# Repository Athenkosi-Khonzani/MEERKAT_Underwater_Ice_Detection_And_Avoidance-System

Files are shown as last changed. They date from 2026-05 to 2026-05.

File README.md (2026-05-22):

# MEERKAT — Underwater Ice Detection and Avoidance System

MEERKAT is a small, low-cost Autonomous Underwater Vehicle (AUV) designed to detect and avoid sub-surface ice (frazil ice, brash ice, and submerged keels of icebergs) in turbid polar waters. The platform descends and ascends using a **Variable Buoyancy System (VBS)** — a syringe driven by two DC motors — rather than thrusters, which keeps power consumption low and the acoustic signature small.

This repository contains the full design package: mechanical CAD, the power-electronics PCB, and the embedded firmware that runs the vehicle.

---

## System Architecture

MEERKAT is divided into four independent subsystems. Each lives in its own folder and has its own README with the wiring, build, and flashing details.

```
                      ┌──────────────────────────────┐
                      │      Surface ESP32           │
                      │  (mission start / telemetry) │
                      └──────────────┬───────────────┘
                                     │ UART (115200 8N1)
                                     │ JSON telemetry  /  "M:1" mission cmd
                ┌────────────────────┴────────────────────┐
                │   Control & Actuation Subsystem (F446)  │
                │   Mission state machine, motor PWM,     │
                │   VBS limit logic, battery monitoring   │
                └─┬──────────────┬──────────────┬─────────┘
                  │ I²C          │ UART         │ PWM
                  │              │              │
        ┌─────────▼────────┐ ┌───▼────────┐ ┌──▼───────────────┐
        │  INA219          │ │ DYP-L08    │ │ Dual DC motors   │
        │  (pack V / I)    │ │ Ultrasonic │ │ on VBS syringe   │
        └──────────────────┘ │ (obstacle) │ └──────────────────┘
                             └────────────┘
                  │ I²C
        ┌─────────▼────────────┐
        │  VL53L1X ToF         │
        │  (plunger position)  │
        └──────────────────────┘

        ┌──────────────────────┐    ┌──────────────────────┐
        │  Power Subsystem     │    │  Housing Subsystem   │
        │  3S Li-ion + TPS5430 │    │  Pressure vessel +   │
        │  → 5 V & 3V3 rails   │    │  motor / VBS mounts  │
        └──────────────────────┘    └──────────────────────┘
```

| Subsystem | What it does | Tech |
|---|---|---|
| **Control & Actuation** | Mission state machine; drives the VBS motors; reads sensors; speaks to the surface ESP32. | STM32F446RET6 (Nucleo-F446RE), STM32CubeIDE, HAL |
| **Sensory** | Stand-alone test firmware for the two ranging sensors used on the vehicle. | STM32F051C6T6, STM32CubeIDE, HAL |
| **Power** | 3S Li-ion pack regulated to a 5 V and a 3.3 V rail; INA219 pack monitor; SoC estimator firmware module. | KiCad 7, TPS5430DDAR buck regulators, INA219 |
| **Housing** | Watertight pressure vessel with separate compartments for the battery, two veroboards, and the syringe / motor assembly. | SolidWorks (`.SLDPRT`) |

---

## Mission Concept of Operations
 
1. **Surface idle.** Pack voltage is monitored. The vehicle waits for a `"M:1"` command from the surface ESP32 over UART3.
2. **Pre-descent check.** The plunger is forced to its minimum position (syringe empty of water). If the battery is below the warning threshold, the mission is refused.
3. **Descend.** The motor is driven forward through the H-bridge; the plunger is pushed out to its maximum position, the syringe pulls water in, and the vehicle sinks.
4. **Submerged loop.** The vehicle stays down for a configurable mission time. Throughout, it:
   * streams JSON telemetry to the surface every 500 ms (SoC, ToF, sonar, MCU temperature),
   * watches the upward-looking DYP-L08 ultrasonic for obstacles closer than 1 m,
   * watches the battery and aborts to ascent if SoC < 20 %.
5. **Ascend.** Once the mission timer expires *and* the path above is clear, the motor is driven in reverse through the H-bridge — the plunger is pulled back in, the syringe expels water, and the vehicle rises. If an obstacle is detected above, the ascent waits for it to clear.
The state machine is implemented in `Control And Actuation Subsystem/Control_System_2.0/Core/Src/main.c`.

---

## Repository Layout

```
.
├── Control And Actuation Subsystem/   # STM32CubeIDE project — main flight firmware
├── Sensory Subsystem/                 # STM32CubeIDE project — sensor bring-up firmware
├── Power Subsystem/                   # KiCad PCB project + SoC estimator source
└── Housing Subsystem/                 # SolidWorks part files for the pressure vessel
```

Each folder has its own README that covers wiring, build instructions, and any setup gotchas. Start there for hands-on work.

---

## Getting Started

### Firmware (Control & Sensory)
1. Install **STM32CubeIDE 1.13** or later.
2. `File → Open Projects from File System…` and point it at the `Control_System_2.0` or `Sensor_Test` folder.
3. Build (`Project → Build All`).
4. Connect the ST-Link, then `Run → Debug` to flash.

The Control subsystem expects a **one-shot calibration** the very first time it is flashed onto a new board — the procedure is documented in its README and is gated by an `#ifdef`-style block in `main.c`.

### PCB (Power)
1. Install **KiCad 7** or later.
2. Open `Power Subsystem/PCB/KHNATH002_Power_System/KHNATH002_Power_System.kicad_pro`.
3. The fabrication outputs for JLCPCB are under `jlcpcb/`.

### Mechanical (Housing)
The parts are `.SLDPRT` files for **SolidWorks 2022** or later. They have not yet been packaged into an assembly file — open each part individually.

---

## Status

| Subsystem | Hardware | Firmware | Verified end-to-end |
|---|:---:|:---:|:---:|
| Control & Actuation | ✅ | ✅ | ✅ |
| Sensory | ✅ | ✅ | ✅ |
| Power | ✅ | ✅ | ⚠️ bench-tested only |
| Housing | ✅ | n/a | ⚠️ dry-fit only |

---

## Authors

EEE4113F project, University of Cape Town, Department of Electrical Engineering.

* Athenkosi Khonzani — Power Subsystem 
* Ayanda Madlala — Housing Subsystem 
* Branden Nkhahle — Sensory Subsystem
* Manelisi Ngcobo — Control And Actuation Subsystem

---

## License

Unless otherwise noted, source code is provided as-is for academic use. STM32 HAL drivers are distributed under their original STMicroelectronics license (see `Drivers/` directory in each firmware project).

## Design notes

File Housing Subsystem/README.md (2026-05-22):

# MEERKAT AUV: Housing Subsystem

## Overview
This subsystem is the **mechanical pressure vessel** for the MEERKAT AUV. Its job is to keep the electronics, the battery, and the Variable Buoyancy System (VBS) syringe dry while the vehicle is submerged, and to provide a rigid mounting point for the single DC motor that drives the VBS plunger.

All parts are designed in **SolidWorks** (version 2022 or later). They are supplied as individual `.SLDPRT` files — there is no master `.SLDASM` assembly in the repo yet.

---

## Parts in this Folder

| File | Purpose |
|---|---|
| `FullBody.SLDPRT` | Outer cylindrical hull of the AUV. Defines the overall envelope and the end-cap interfaces. |
| `Imporved Upper Lid.SLDPRT` | Top end cap. Carries the through-hull port for the **upward-looking ultrasonic sensor** (used during ascent to check the path is clear of ice). *(filename typo preserved for git history.)* |
| `Improved lowe lid.SLDPRT` | Bottom end cap. Mounts the `Circular motor holder` on its inner face and provides the wet-side opening for the VBS syringe. *(filename typo preserved for git history.)* |
| `Circular motor holder.SLDPRT` | Bulkhead bracket fixed to the lower lid; locates and clamps the **single DC motor** that drives the VBS syringe plunger. |
| `Compartment battery.SLDPRT` | Internal tray that holds the 3S Li-ion pack and keeps it isolated from the veroboards. |
| `Compartment 2 veroboard.SLDPRT` | Internal mounting tray for the power-electronics veroboard (regulators + INA219). |
| `Compartment3 veroboard.SLDPRT` | Internal mounting tray for the Control & Actuation veroboard (STM32F446 carrier + sensor breakouts). |

---

## Internal Layout

The hull is divided into three stacked compartments along its axis, with the motor and VBS syringe mounted at the bottom:

```
   ┌──────────────────────────────────────────────────────────┐
   │                  Upper Lid                               │  ← upward-looking ultrasonic port
   ├──────────────────────────────────────────────────────────┤
   │   Compartment 3   — Control veroboard (STM32F446 + I/O)  │
   ├──────────────────────────────────────────────────────────┤
   │   Compartment 2   — Power veroboard (TPS5430 + INA219)   │
   ├──────────────────────────────────────────────────────────┤
   │   Battery Compartment — 3S Li-ion pack                   │
   ├──────────────────────────────────────────────────────────┤
   │                  Lower Lid                               │  ← carries Circular Motor Holder
   │   Circular Motor Holder — 1 × DC motor → VBS syringe     │
   └──────────────────────────────────────────────────────────┘
```

The arrangement keeps the **heaviest component (battery) low** to give the vehicle a stable righting moment, and isolates the **noisy power electronics** in their own compartment so they do not couple into the sensor / MCU veroboard above. Mounting the motor and VBS at the bottom also keeps the wet-side syringe opening submerged for the entire mission.

---

## Sealing Strategy
* End caps mate against the outer body via an **O-ring face seal** on each lid.
* The **upper lid** carries the upward-looking ultrasonic sensor — its housing is sealed against the lid, and a cable gland alongside it passes the sensor's power and signal wires into the dry compartment below.
* The **lower lid** carries the VBS syringe opening (wet side) and the through-bolts that hold the `Circular motor holder` against its dry-side face.
* The motor holder itself is **internal only** — it is not a sealing surface; it just constrains the motor body axially and radially so the plunger reaction force does not deflect it.

---

## Manufacturing Notes
* The lids and internal compartments are intended for **3D printing** (PLA or PETG for prototypes, ABS or nylon for water trials).
* The cylindrical `FullBody` is a **PVC pipe section** that the lids press into — the part file captures the inner diameter against which the lid O-rings seal.
* Allow O-ring squeeze of **15–20 %** when you print final lids; PLA prints loose by ~0.2 mm on diameter.

---

## Opening the Files
1. Open **SolidWorks 2022** or later.
2. `File → Open` and select any `.SLDPRT`.
3. Each part is self-contained and has no external references — they can be opened in any order.

If you build an assembly, recommended mate order:
1. Insert `FullBody` (fix in space).
2. Mate the two lids to its end faces.
3. Mate `Circular motor holder` against the **inner face of the lower lid**.
4. Stack the three compartment trays inside the body, working upward from the battery tray.

---

## Status & Known Issues
* Two part filenames have typos (`Imporved`, `lowe`) — preserved to avoid breaking git history. Renaming them is safe but should be done in a single commit and announced to anyone with the repo open.
* The repo does **not yet contain a top-level assembly file** (`.SLDASM`) or a drawing pack (`.SLDDRW`). These should be added before the design is taken to manufacturing.
* No tolerance analysis has been documented for the O-ring grooves yet — verify against the supplier's recommended squeeze before committing to a print.
* The motor-holder bracket has been dry-fit only; it has not been tested under the full single-motor plunger reaction force in water.

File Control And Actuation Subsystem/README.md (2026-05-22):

# MEERKAT AUV: Control & Actuation Subsystem Firmware (STM32F446RE)

## Overview
This is the **flight firmware** for the MEERKAT Autonomous Underwater Vehicle (AUV). It runs on an STM32F446RET6 (Nucleo-F446RE) and is responsible for the full mission state machine:

* Receiving the mission-start command from the surface ESP32.
* Driving the **Variable Buoyancy System (VBS)** — two DC motors that push and pull a syringe plunger — to descend and ascend.
* Reading the **VL53L1X ToF** sensor as a software-defined limit switch on the plunger.
* Reading the **DYP-L08-V2.0 ultrasonic** sensor for obstacle / ice detection on the ascent path.
* Reading the **INA219** to track battery State of Charge (SoC) and abort the mission if it drops below threshold.
* Streaming JSON telemetry back to the surface every 500 ms.

The project is built with **STM32CubeIDE** against the STM32F4 HAL.

---

## Hardware & Pin Configuration (.ioc mapping)

The target is `STM32F446RETx`. Pin assignments are taken from `Control_System_2.0.ioc` and `Core/Inc/main.h`.

### 1. VL53L1X ToF Sensor (I²C2) — plunger position
* SCL: **PB10** (I2C2_SCL)
* SDA: **PC12** (I2C2_SDA)
* XSHUT: **PA8** (`XShunt_Pin`, GPIO output — pulsed low/high in `main()` to release the sensor from reset)
* I²C address: `0x52` (8-bit shifted)

### 2. INA219 Battery Monitor (I²C1)
* SCL: **PB8** (I2C1_SCL)
* SDA: **PB7** (I2C1_SDA)
* I²C address: `0x40` (7-bit) → `0x80` (8-bit)

### 3. DYP-L08-V2.0 Ultrasonic Sensor (USART1)
* TX (MCU → sensor trigger): **PA9** (USART1_TX)
* RX (sensor → MCU 4-byte frame): **PA10** (USART1_RX)
* Baud rate: **115 200, 8N1**
* Protocol: MCU writes `0x55` to trigger; sensor responds with `[0xFF][D_H][D_L][SUM]`.

### 4. VBS Motor Drive (TIM3 / TIM4 PWM)
* Motor 1 PWM (push plunger → **descend**): **PA6** (TIM3_CH1) → `TIM3->CCR1`
* Motor 2 PWM (pull plunger → **ascend**): **PB6** (TIM4_CH1) → `TIM4->CCR1`
* Setting `CCR = 1599` drives the motor at full duty; `CCR = 0` brakes / stops.

### 5. Surface ESP32 Link (USART3)
* TX (telemetry out): **PC10** (USART3_TX)
* RX (mission-cmd in): **PC5** (USART3_RX, asynchronous)
* Baud rate: **115 200, 8N1**
* RX interrupt is armed in `MissionRx_Init()` — when `"M:1\n"` arrives, the global `missionInit` flag is set.

### 6. User Interface
* User button (Nucleo B1): **PC13** (`Pushbutton_Pin`, EXTI13, falling edge) — alternative way to start the mission via `HAL_GPIO_EXTI_Callback()`.
* Status LED (Nucleo LD2): **PA5** (`LD2_Pin`) — solid ON during the active mission, used as the calibration prompt LED.

### 7. Debugging (SWD)
* SWDIO: **PA13**, SWCLK: **PA14**, SWO: **PB3** — locked open in CubeMX so the ST-Link cannot be locked out.

### 8. MCU Internal Temperature
* **ADC1** sampling the internal `ADC_CHANNEL_TEMPSENSOR` via DMA — used for the `mcu_temp` field in telemetry.

### 9. Real-Time Clock
* **LSE** crystal on **PC14/PC15** drives the RTC, which timestamps the mission duration.

---

## Mission State Machine (`main.c`)

The flight loop in `main()` implements the following gated flow. Each iteration begins with a fresh RTC snapshot, `UpdateSensors()`, and a non-blocking `Telemetry_Tick()`.

```
                ┌────────────────────────────────┐
                │ Wait for missionInit ("M:1")   │
                └──────────────┬─────────────────┘
                               │
                ┌──────────────▼─────────────────┐
                │ Battery enough?  (SoC > 30 %)  │── no ──► stop_motor(); maybe ascend()
                └──────────────┬─────────────────┘
                               │ yes
                ┌──────────────▼─────────────────┐
                │ Plunger at MIN?                │── no ──► Force_plunger_min(); loop
                └──────────────┬─────────────────┘
                               │ yes
                ┌──────────────▼─────────────────┐
                │ descend()  — TIM3 PWM full     │
                └──────────────┬─────────────────┘
                               │
                ┌──────────────▼─────────────────┐
                │ Submerged dwell loop           │
                │  while !mission_complete       │
                │        && SoC >= 20 %          │
                └──────────────┬─────────────────┘
                               │ timer / battery
                ┌──────────────▼─────────────────┐
                │ ascend()  — TIM4 PWM, blocks   │
                │ if sonar_dist < 1000 mm        │
                └────────────────────────────────┘
```

Key constants in `main.c`:
* `MIN = 65`, `MAX = 100` — VBS plunger limits in mm (linear ToF reading after calibration).
* Sonar safety threshold: ascent will not proceed if `sonar_dist <= 1000 mm`.
* Mission timeout: currently `30 s` (line `if (time_elapsed >= 30)`) — change here to extend dives.
* `TELEM_PERIOD_MS = 500` — telemetry packet rate.

---

## Core File Structure

### `main.c`
The mission state machine described above. Hosts the helpers `stop_motor()`, `Force_plunger_min()`, `descend()`, `ascend()`, and `UpdateSensors()`. It also contains a **one-shot ToF calibration routine** (`RunOneShotCalibration()`) which is normally commented out — see the *First-Flash Calibration* section below.

### `ToF.c` / `ToF.h`  (`Core/Inc/`)
Driver and calibration logic for the VL53L1X.
* **Two-point linear calibration.** Reference points are `TOF_CAL_NEAR_REF_MM = 60` and `TOF_CAL_FAR_REF_MM = 120`. The driver averages `TOF_CAL_SAMPLES = 50` raw samples at each point and computes a slope/offset that maps the sensor's distorted reading inside the syringe housing to true millimetres.
* **Persistent storage.** Slope and offset are saved through `FlashStore_*` to **Flash Sector 7** (`0x08060000`) so calibration survives a power cycle.
* Both raw and calibrated reads are exposed (`ToF_ReadDistanceRaw()` / `ToF_ReadDistance()`).

### `Sonar.c` / `Sonar.h`  (`Core/Inc/`)
DYP-L08-V2.0 driver over UART1.
* `Sonar_GetDistance()` sends the `0x55` trigger byte, then blocks up to 100 ms waiting for the 4-byte reply.
* **Frame validation:** header byte (`0xFF`), checksum (`(uint8_t)(0xFF + D_H + D_L)`), and explicit reject of `0x0000` / `0xFFFF` out-of-range sentinels.
* Returns a structured `Sonar_Status` enum so the caller can distinguish a TX timeout from a bad checksum from a true out-of-range reading.

### `battery.c` / `battery.h`  (`Core/Inc/`)
INA219-based State-of-Charge estimator. Default configuration is for the **3S 1000 mAh Li-ion pack** used in the vehicle (full = 12.6 V, empty = 8.4 V). Combines an **OCV lookup table** (used once at boot for the initial SoC seed) with **coulomb counting** during operation. Exposes a `BatteryData_t` snapshot through `Battery_GetData()` and three status flags (`BATTERY_OK / WARNING / CRITICAL`).

### `telemetry.c` / `telemetry.h`  (`Core/Inc/`)
Builds and transmits a newline-terminated JSON telemetry packet over USART3 (to the surface ESP32). One packet contains: sequence number, SoC %, pack voltage, pack current, ToF mm, sonar mm, MCU temperature. Sentinel values `TELEM_DIST_INVALID` (`0xFFFF`) and `TELEM_TEMP_INVALID` (`-999.0`) flag unavailable sensors.

### `mission_rx.c` / `mission_rx.h`  (`Core/Inc/`)
Receives mission commands from the surface ESP32 on USART3 via interrupt. The only command currently parsed is `"M:1"`, which sets the global `missionInit` flag and unblocks the main loop.

### `temp_sensor.c` / `temp_sensor.h`  (`Core/Inc/`)
Thin wrapper around the STM32's internal temperature sensor on ADC1 (DMA-driven), returning a calibrated temperature in °C.

### `FlashStore.c` / `FlashStore.h`  (`Core/Inc/`)
Two-function persistent-storage helper (`FlashStore_Load`, `FlashStore_Save`) used by `ToF.c` to keep the calibration record across reboots. Storage lives in **Flash Sector 7** (`0x08060000`, 128 KB). The linker script (`STM32F446RETX_FLASH.ld`) must cap application FLASH at `0x60000` to keep code out of that sector — this has already been done.

> **Note:** Driver and configuration sources for the I²C, UART, RTC, ADC, and TIM peripherals were generated by CubeMX and live in `Core/Src/`. Pin assignments are described above and are the source of truth.

---

## First-Flash Calibration (one-shot, then re-flash)

The very first time you flash this firmware onto a fresh board, the ToF needs its two-point calibration captured against the **actual** syringe housing. The procedure lives in `RunOneShotCalibration()` in `main.c`:

1. Uncomment the call to `RunOneShotCalibration(&hi2c2)` in `main()`.
2. Place a flat target exactly **60 mm** from the sensor face.
3. Flash and reset. LD2 stays on for 5 s — get ready.
4. LD2 turns off and the firmware captures 50 samples (~3 s).
5. LD2 comes back on for 5 s — move the target to exactly **120 mm**.
6. LD2 turns off, 50 more samples are captured.
7. **3 quick flashes = success.** The slope/offset are saved to Flash Sector 7. Solid-on LED = failure.
8. Re-comment the `RunOneShotCalibration()` call and re-flash with the production build.

The calibration record is persistent — you do **not** need to repeat this between subsequent flashes of the production firmware unless you erase the chip or change syringe geometry.

---

## Building & Flashing

1. Open **STM32CubeIDE 1.13** or later.
2. `File → Open Projects from File System…` → select the `Control_System_2.0/` folder.
3. `Project → Build All`.
4. Plug in the Nucleo (ST-Link enumerates over USB).
5. `Run → Debug` to flash and start a debug session, or `Run → Run` to flash and detach.

The default build output is `Debug/Control_System_2.0.elf`.

---

## Quick Troubleshooting

| Symptom | Likely cause |
|---|---|
| LED blinks fast forever right after boot | `ToF_Init()` failed — check XShunt (PA8) wiring and I²C2 pull-ups on PB10/PC12. |
| LED solid on, never starts mission | `Battery_Init()` returned `HAL_ERROR` — check INA219 wiring and address (0x40) on I²C1 (PB7/PB8). |
| Vehicle never descends after `"M:1"` is sent | Plunger is already at MAX — `Force_plunger_min()` is running first; give it ~10 s. |
| Telemetry stops mid-mission | UART3 wire on PC10 disconnected, or surface ESP32 reset. |
| Vehicle stays down past mission time | Sonar reading is below 1000 mm — something is above the AUV blocking the ascent. |
| ST-Link suddenly cannot connect | SWD pins (PA13/PA14) somehow got remapped — hold the BOOT0 button on power-up to force the system bootloader, then re-flash. |

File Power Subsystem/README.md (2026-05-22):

# MEERKAT AUV: Power Subsystem

## Overview
This subsystem is the **power-distribution and monitoring** layer of the MEERKAT AUV. It takes a 3-cell (3S) Li-ion battery pack and produces the two regulated rails the rest of the vehicle needs (**5 V** and **3.3 V**), while continuously measuring pack voltage and current so the flight firmware can estimate state of charge and abort the mission before the battery dies underwater.

The deliverable is two parts:

1. A **KiCad PCB project** (`PCB/KHNATH002_Power_System/`) implementing the regulators and the INA219 monitor.
2. A **portable C firmware module** (`SOC/`) — `battery.c`/`battery.h` — that runs on the flight MCU and turns INA219 readings into a usable SoC + runtime estimate.

---

## Hardware

### Battery Pack
* **Topology:** 3S Li-ion (three 18650-format cells in series).
* **Capacity:** 1000 mAh nominal (series cells share the pack mAh, they do not multiply).
* **Voltage range:**
  * Full = 3 × 4.20 V = **12.60 V**
  * Empty (cutoff) = 3 × 2.80 V ≈ **8.4 V** (configurable via `BAT_VOLTAGE_EMPTY_V`)

### Regulators (`TPS_Regulators.kicad_sch`)
Two **TPS5430DDAR** synchronous-buck regulators step the pack voltage down to the vehicle's two rails:

| Rail | Regulator | Loads |
|---|---|---|
| **5 V** | TPS5430DDAR | DC motors (via H-bridge driver), DYP-L08 ultrasonic sensor |
| **3.3 V** | TPS5430DDAR | STM32F446 MCU, VL53L1X ToF, INA219, ESP32 link |

The TPS5430 is rated 5.5–36 V in, 3 A continuous, with an internal high-side MOSFET — chosen for the headroom over the 12.6 V pack and for the relatively low BOM cost.

> **Note:** An earlier version of the design used the **MP2338GTL** (see `Regulators.kicad_sch`). That sheet is kept in the repo for history but is **not** part of the current top sheet (`KHNATH002_Power_System.kicad_sch`). The TPS implementation is the one that goes to fab.

### Monitoring (`Monitoring.kicad_sch`)
* **INA219** — high-side I²C current/voltage monitor sitting on the pack output, before the regulators. Configured for the 32 V bus-voltage range (the 16 V range saturates on a freshly charged 3S pack) and the /8 gain (320 mV full-scale on the shunt).
* **Shunt:** 0.1 Ω, giving a 100 µA current LSB after calibration → **CAL register = 4096**.
* **I²C address:** `0x40` (7-bit).

The INA219 talks to the flight MCU over **I²C1 (PB7 / PB8)** — see the Control & Actuation Subsystem README.

---

## PCB Layout

The KiCad project lives under:

```
Power Subsystem/PCB/KHNATH002_Power_System/
├── KHNATH002_Power_System.kicad_pro      # top-level project
├── KHNATH002_Power_System.kicad_sch      # top hierarchical sheet
├── KHNATH002_Power_System.kicad_pcb      # board layout
├── TPS_Regulators.kicad_sch              # 5V + 3V3 buck regulators (active)
├── Monitoring.kicad_sch                  # INA219 pack monitor
├── Regulators.kicad_sch                  # MP2338 regulators (legacy, unused)
└── jlcpcb/                               # fabrication outputs for JLCPCB
```

Open `KHNATH002_Power_System.kicad_pro` in **KiCad 7** or later.

---

## Firmware Module — `SOC/`

`battery.c` / `battery.h` is the on-board **State-of-Charge and runtime estimator**. It is not a stand-alone program — it links into the Control & Actuation Subsystem firmware (see that subsystem's README for how it is wired in).

### Algorithm
1. **Seed.** At init, read the open-circuit pack voltage (OCV) from the INA219 and map it through a lookup table to get the starting SoC. This compensates for the unknown charge state at power-on.
2. **Coulomb count.** Every `BAT_SAMPLE_PERIOD_MS` (default 500 ms), read voltage + current, then integrate current × Δt into a running `used_mAh` figure.
3. **OCV correction.** Resting-voltage measurements are blended into the coulomb-counted SoC slowly so the estimate self-corrects over time without jumping under load.
4. **Runtime.** Remaining mAh divided by recent-average current gives a live `runtime_sec` figure exposed via `Battery_GetData()`.

### Public API
```c
HAL_StatusTypeDef Battery_Init(I2C_HandleTypeDef *hi2c);
HAL_StatusTypeDef Battery_Update(void);
void              Battery_GetData(BatteryData_t *out);
void              Battery_RuntimeToHMS(uint32_t s, uint32_t *h, uint32_t *m, uint32_t *sec);
```

### `BatteryData_t` snapshot
```c
float   soc_pct;        // 0.0 – 100.0
float   voltage_V;      // pack terminal voltage
float   current_A;      // positive = discharging
float   used_mAh;       // since boot
float   remaining_mAh;
uint32_t runtime_sec;
BatteryStatus_t status; // OK / WARNING / CRITICAL
bool    valid;
```

### Configurable thresholds (in `battery.h`)
| Macro | Default | Meaning |
|---|---|---|
| `BAT_SERIES_CELLS` | 3 | Cells in series — adjust if pack changes. |
| `BAT_CAPACITY_MAH` | 1000 | Rated pack capacity (mAh). |
| `BAT_VOLTAGE_FULL_V` | 12.60 | Full pack voltage. |
| `BAT_VOLTAGE_EMPTY_V` | 8.40 | Cutoff. |
| `BAT_VDIV_RATIO` | 1.0 | Set to your divider ratio if INA219 V+ sees less than full pack voltage. |
| `BAT_SOC_OK_THRESHOLD` | 60 % | Above this → `BATTERY_OK`. |
| `BAT_SOC_WARNING_THRESHOLD` | 30 % | Above this → `BATTERY_WARNING`. Below → `BATTERY_CRITICAL`. |
| `BAT_SAMPLE_PERIOD_MS` | 500 | Coulomb-count integration period. |

The flight firmware uses these directly:
* SoC ≤ **30 %** → motor commands refused; pre-descent gate trips.
* SoC < **20 %** → in-mission abort; vehicle ascends if the path is clear.

---

## Build & Flash (firmware module)
The module is built as part of the Control & Actuation Subsystem firmware. To use it stand-alone in another project:

1. Copy `SOC/battery.c` and `SOC/battery.h` into your project.
2. Include `"battery.h"` in your `main.c`.
3. After your I²C peripheral is initialised, call `Battery_Init(&hi2c1)`.
4. Call `Battery_Update()` in your main loop (it rate-limits itself internally).
5. Read data with `Battery_GetData(&snapshot)`.

The module depends only on the STM32 HAL I²C driver — no other RTOS or library.

---

## Voltage-Divider Note (read this before powering up)

The INA219's bus-voltage input is rated to 26 V max but its 16 V config-register mode saturates above ~16 V. The 3S pack peaks at 12.6 V, which is well inside the 26 V hardware limit — **so this design connects V+ directly to the pack**, and `BAT_VDIV_RATIO` is set to `1.0`.

If you re-spin the board with a divider (e.g. for a 4S pack), update `BAT_VDIV_RATIO` in `battery.h` to the new divider ratio so the firmware un-scales the reading correctly.

---

## Status & Known Issues
* The TPS5430 layout has been verified on the bench but **not yet integrated under load with the full vehicle**.
* `Regulators.kicad_sch` (MP2338 variant) is kept in the repo for history. It is **not** part of the current build.
* The schematic does not yet include explicit reverse-polarity protection on the battery input — a Schottky or P-FET is recommended for the next revision.

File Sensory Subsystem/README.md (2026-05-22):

# MEERKAT AUV: Sensory Subsystem Firmware (STM32F411)

## Overview
This repository contains the STM32CubeIDE project for the Sensory Subsystem of the MEERKAT Autonomous Underwater Vehicle (AUV). This subsystem provides critical internal proprioception (Variable Buoyancy System limits) and external exteroception (underwater obstacle avoidance) for the platform.

The firmware successfully integrates two primary sensors:

1. VL53L1X Time-of-Flight (ToF) Sensor: Acts as a continuous, software-defined proximity limit switch to track the linear displacement of the VBS syringe plunger (40mm to 120mm limits).
2. DYP-L08-V2.0 Ultrasonic Sensor: Provides long-range (up to 10m) acoustic obstacle and ice detection in highly turbid Antarctic waters.

## Hardware & Pin Configuration (.ioc mapping)
The project is configured for the STM32F411 microcontroller. The .ioc file contains the following critical pin mappings and peripheral configurations:

### 1. VL53L1X ToF Sensor (I2C1)
- Protocol: I2C (Address: 0x52 - 8-bit shifted)
- SCL: PB6 (or as defined in your .ioc)
- SDA: PB7 (or as defined in your .ioc)

### 2. DYP-L08-V2.0 Ultrasonic Sensor (UART2 / GPIO)
- Protocol: UART (Baud Rate: 115200, 8N1)
- Trigger Pin (Yellow Wire): PA0 (Configured as GPIO Output. MCU pulls this LOW for 1ms to trigger a ping).
- Data RX Pin (White Wire): PA3 (USART2_RX. Receives the 4-byte distance frame).

### 3. Debugging & Failsafe (SWD)
- SWDIO: PA13
- SWCLK: PA14
- Note: The debug pins are explicitly locked open in the firmware (GPIO_MODE_AF_PP, GPIO_AF0_SWJ) to prevent the ST-Link from being locked out during sleep states or clock reconfigurations.

---

## Core File Structure (/Core/Src and /Core/Inc)

### main.c
Handles the primary boot sequence, peripheral initialization, and main execution loop.
- Safe Boot Sequence: On startup, main.c checks the internal Flash memory for a saved calibration profile. If found, it bypasses setup. If missing, it forces the AUV into a calibration state, prompting the user to manually move the syringe to the 20mm and 120mm bounds.
- Hardware Failsafe: Explicitly enables the GPIOA clock and maps PA13/PA14 to the debugger immediately after the system clock configuration to prevent SWD lockouts.

### ToF.c & ToF.h
Contains the drivers, mathematical filters, and memory management for the Variable Buoyancy limit switch.
- Two-Point Linear Calibration: Calculates a dynamic multiplier (m) and offset (b) using ToF_Calibrate_TwoPoint() to mathematically eliminate optical crosstalk caused by the confined syringe housing.
- Sliding Window Median Filter: Buffers distance samples and extracts the median to reject violent optical scatter spikes before they trigger a false motor-stop.
- Non-Volatile Memory Management: Saves the m and b floats permanently into Flash Sector 5 (Address 0x08020000).

### Sonar.c & Sonar.h (or equivalent UART parsing logic)
Handles the acoustic ranging data for collision avoidance.
- Frame Parsing: Reconstructs the physical distance by bit-shifting the High and Low bytes received over UART.
- Checksum Validation: Discards corrupted UART frames to prevent erratic avoidance maneuvers.
- Moving Average Filter: Smooths incoming readings to mitigate false positives caused by localized bubble swarms or water currents.

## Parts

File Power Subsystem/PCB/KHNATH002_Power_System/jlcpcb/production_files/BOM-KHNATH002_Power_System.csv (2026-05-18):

Comment | Designator | Footprint | LCSC | Quantity
0.01u | C5,C6 | C_0603_1608Metric_Pad1.08x0.95mm_HandSolder | C57112 | 2
0.1u | C2 | C_0603_1608Metric_Pad1.08x0.95mm_HandSolder | C14663 | 1
10k | R1,R7 | R_0603_1608Metric_Pad0.98x0.95mm_HandSolder | C25804 | 2
10u | C1,C3,C4 | C_0603_1608Metric_Pad1.08x0.95mm_HandSolder | C19702 | 3
12k | R6 | R_0603_1608Metric_Pad0.98x0.95mm_HandSolder | C22790 | 1
20k | R5 | R_0603_1608Metric_Pad0.98x0.95mm_HandSolder | C4184 | 1
2m | R4 | R_2512_6332Metric_Pad1.40x3.35mm_HandSolder | C2994640 | 1
3.3k | R8 | R_0603_1608Metric_Pad0.98x0.95mm_HandSolder | C22978 | 1
4.7k | R2,R3 | R_0603_1608Metric_Pad0.98x0.95mm_HandSolder | C23162 | 2
B340A | D2,D3 | SMA_L4.3-W2.6-LS5.1-RD | C64982 | 2
INA219AIDR | U2 | SOIC-8_L4.9-W3.9-P1.27-LS6.0-BL | C138706 | 1
LED | D1 | LED_0603_1608Metric_Pad1.05x0.95mm_HandSolder | C2286 | 1
RVT1V221M0810 | U7,U8 | CAP-SMD_BD8.0-L8.3-W8.3-LS9.1-FD | C3340 | 2
SMDRI127-150MT | U5,U6 | IND-SMD_L12.5-W12.5_RLF12545T | C40000 | 2
SS-12D06L5 | U1 | SW-TH_3P-P4.70_L11.1-W12.7 | C319015 | 1
TPS5430DDAR | U3,U4 | ESOP-8_L4.9-W3.9-P1.27-LS6.0-TL-EP | C9864 | 2
Jumper_2_Open | JP3 | SolderJumper-2_P1.3mm_Open_RoundedPad1.0x1.5mm |  | 1
Jumper_2_Open | JP2 | SolderJumper-2_P1.3mm_Open_RoundedPad1.0x1.5mm |  | 1
Jumper_2_Open | JP1 | SolderJumper-2_P1.3mm_Open_TrianglePad1.0x1.5mm |  | 1
GND | GND | TestPoint_Pad_D3.0mm |  | 1
LOAD | M_LOAD | TestPoint_Pad_D3.0mm |  | 1
+12V | TP10 | TestPoint_Pad_D3.0mm |  | 1
Conn_01x02_Pin | J6 | PinHeader_1x02_P2.54mm_Vertical |  | 1
Conn_01x02_Pin | J5 | PinHeader_1x02_P2.54mm_Vertical |  | 1

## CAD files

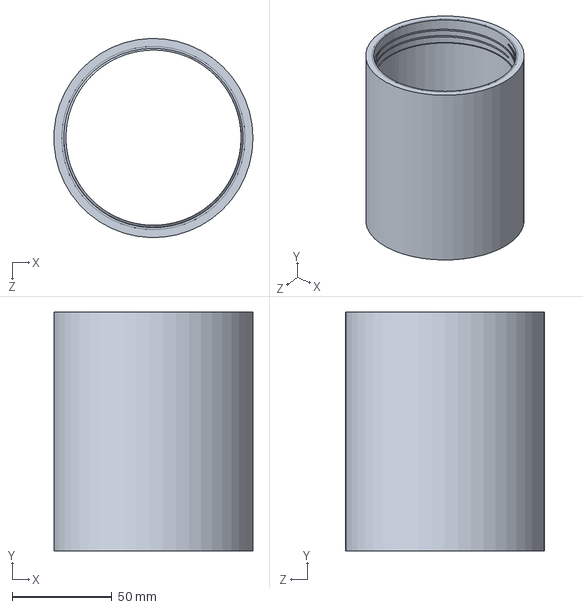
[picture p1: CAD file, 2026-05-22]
Housing Subsystem/FullBody.SLDPRT
99.9 x 120.0 x 99.9 mm

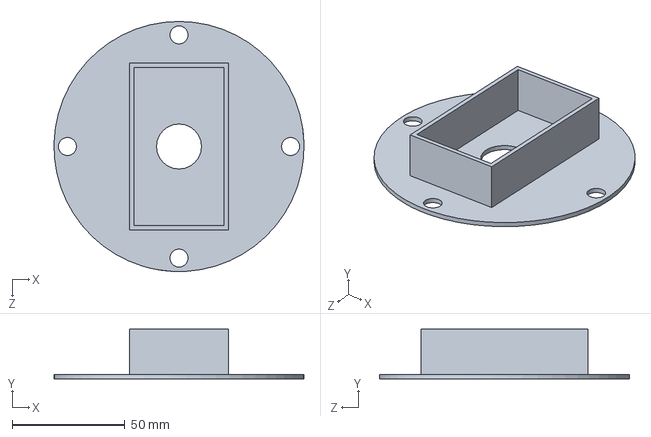
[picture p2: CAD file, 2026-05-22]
Housing Subsystem/Compartment 2 veroboard.SLDPRT
111.0 x 22.0 x 111.0 mm

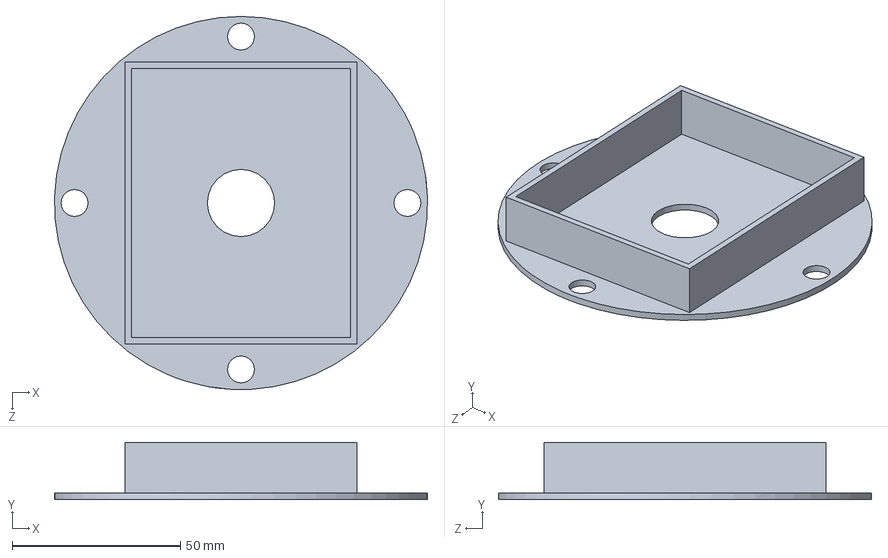
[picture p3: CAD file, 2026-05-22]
Housing Subsystem/Compartment3 veroboard.SLDPRT
111.0 x 17.0 x 111.0 mm

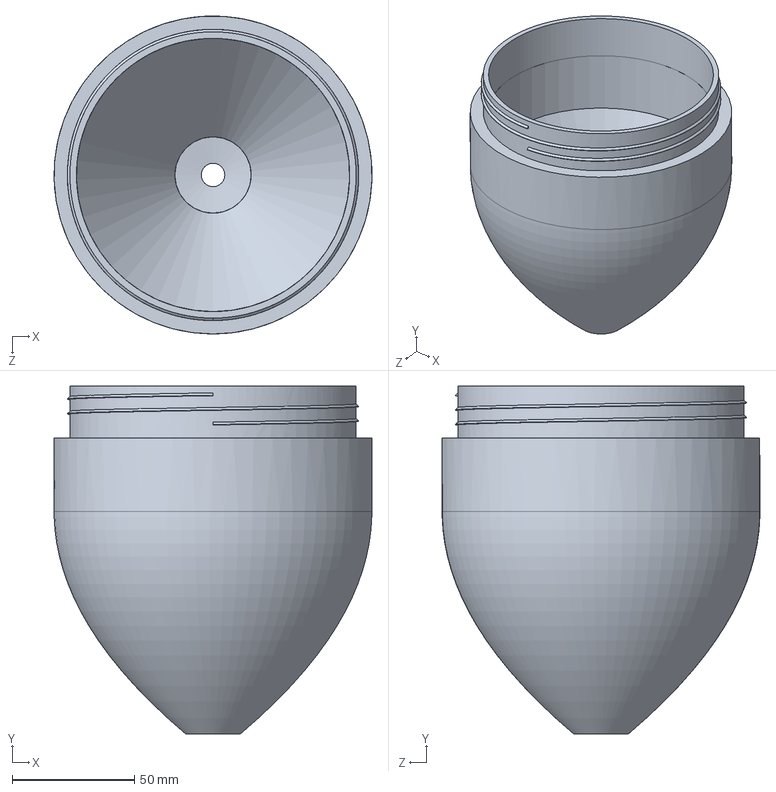
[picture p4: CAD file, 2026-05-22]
Housing Subsystem/Improved lowe lid.SLDPRT
130.0 x 142.3 x 130.0 mm

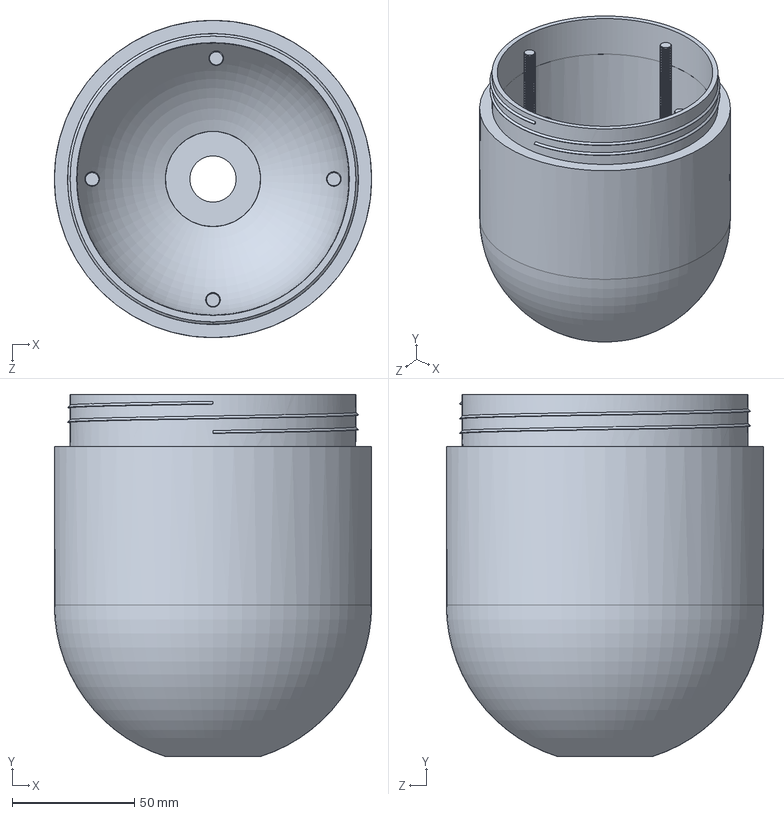
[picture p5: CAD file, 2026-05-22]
Housing Subsystem/Imporved Upper Lid.SLDPRT
130.0 x 148.3 x 130.0 mm

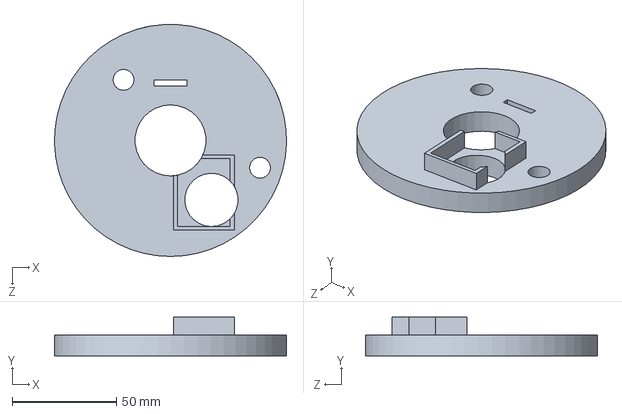
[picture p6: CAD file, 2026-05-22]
Housing Subsystem/Circular motor holder.SLDPRT
111.1 x 18.5 x 111.1 mm

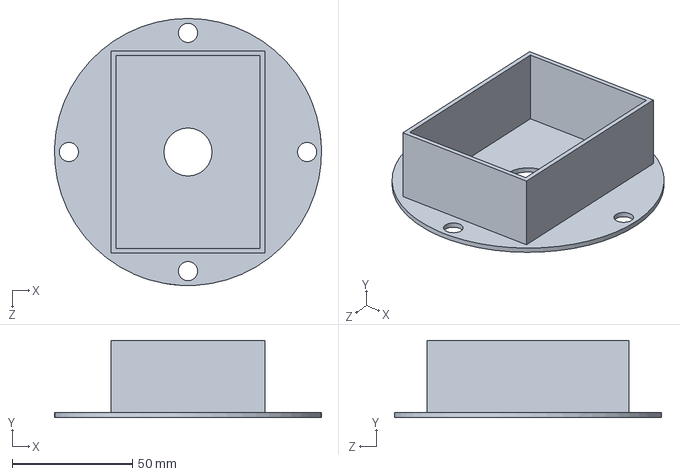
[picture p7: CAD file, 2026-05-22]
Housing Subsystem/Compartment battery.SLDPRT
111.0 x 32.0 x 111.0 mm

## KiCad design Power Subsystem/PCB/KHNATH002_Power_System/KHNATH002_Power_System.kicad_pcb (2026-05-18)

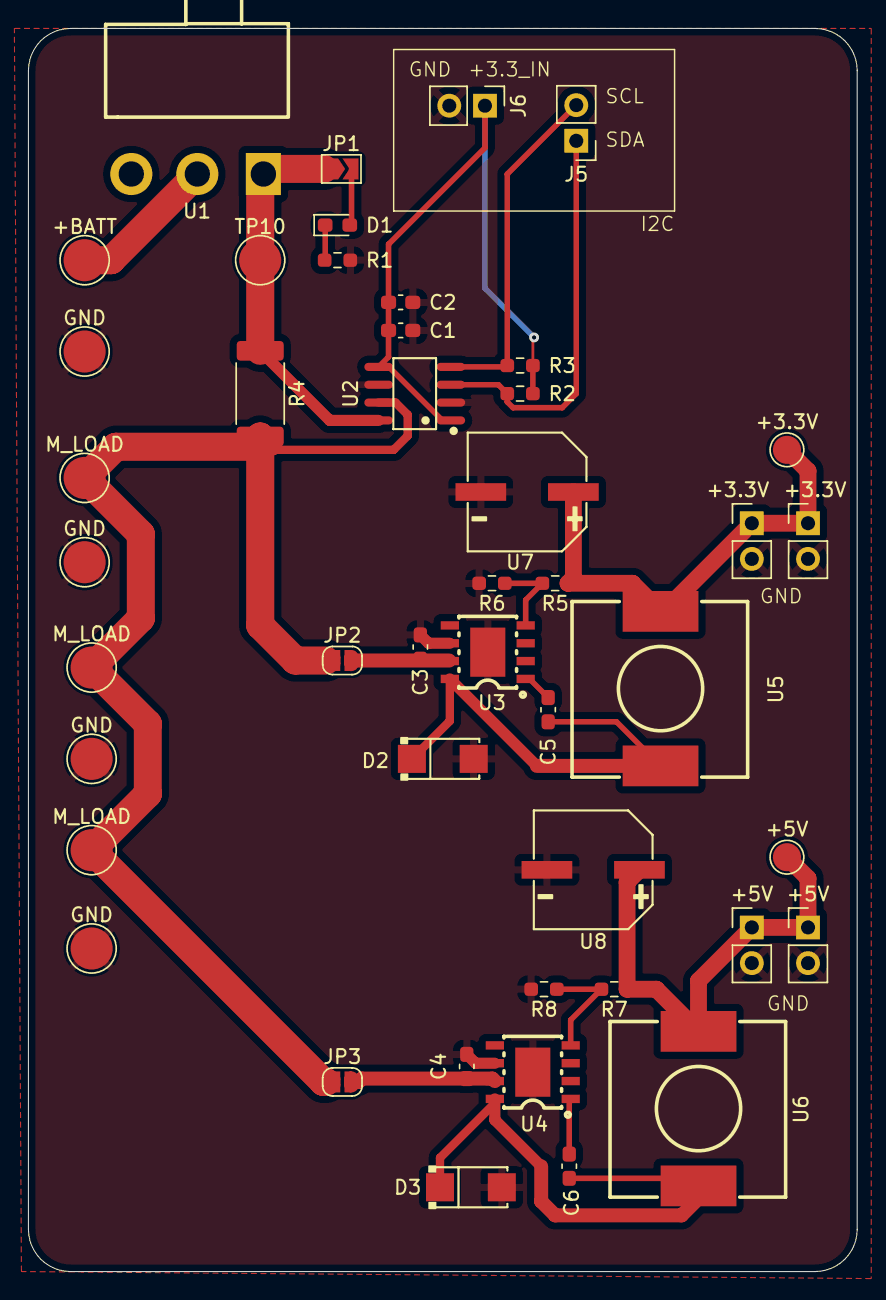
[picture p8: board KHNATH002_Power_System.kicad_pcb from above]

Board: 2 copper layers, 59.0 x 88.5 mm, 45 parts (0 on the bottom side), 19 nets.

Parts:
+3.3V: +3.3V; TestPoint_Pad_D2.0mm
+3.3V#2, +3.3V#3, +5V#2, +5V#3: Conn_01x02_Pin; PinHeader_1x02_P2.54mm_Vertical
+5V: +5V; TestPoint_Pad_D2.0mm
+BATT: +BATT; TestPoint_Pad_D3.0mm
C1, C3, C4: 10u; C_0603_1608Metric_Pad1.08x0.95mm_HandSolder
C2: 0.1u; C_0603_1608Metric_Pad1.08x0.95mm_HandSolder
C5, C6: 0.01u; C_0603_1608Metric_Pad1.08x0.95mm_HandSolder
D1: LED; LED_0603_1608Metric_Pad1.05x0.95mm_HandSolder
D2, D3: B340A; SMA_L4.3-W2.6-LS5.1-RD
GND: GND; TestPoint_Pad_D3.0mm
GND#2, GND#3, GND#4: GND; TestPoint_Pad_D3.0mm
J5, J6: Conn_01x02_Pin; PinHeader_1x02_P2.54mm_Vertical
JP1: Jumper_2_Open; SolderJumper-2_P1.3mm_Open_TrianglePad1.0x1.5mm
JP2, JP3: Jumper_2_Open; SolderJumper-2_P1.3mm_Open_RoundedPad1.0x1.5mm
M_LOAD: LOAD; TestPoint_Pad_D3.0mm
M_LOAD#2, M_LOAD#3: LOAD; TestPoint_Pad_D3.0mm
R1, R7: 10k; R_0603_1608Metric_Pad0.98x0.95mm_HandSolder
R2, R3: 4.7k; R_0603_1608Metric_Pad0.98x0.95mm_HandSolder
R4: 2m; R_2512_6332Metric_Pad1.40x3.35mm_HandSolder
R5: 20k; R_0603_1608Metric_Pad0.98x0.95mm_HandSolder
R6: 12k; R_0603_1608Metric_Pad0.98x0.95mm_HandSolder
R8: 3.3k; R_0603_1608Metric_Pad0.98x0.95mm_HandSolder
TP10: +12V; TestPoint_Pad_D3.0mm
U1: SS-12D06L5; SW-TH_3P-P4.70_L11.1-W12.7
U2: INA219AIDR; SOIC-8_L4.9-W3.9-P1.27-LS6.0-BL
U3, U4: TPS5430DDAR; ESOP-8_L4.9-W3.9-P1.27-LS6.0-TL-EP
U5, U6: SMDRI127-150MT; IND-SMD_L12.5-W12.5_RLF12545T
U7, U8: RVT1V221M0810; CAP-SMD_BD8.0-L8.3-W8.3-LS9.1-FD

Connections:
+3.3V: +3.3V.1, +3.3V#2.1, +3.3V#3.1, R5.1, U5.1, U7.1
+5V: +5V.1, +5V#2.1, +5V#3.1, R7.1, U6.1, U8.1
+12V: JP1.1 (A), R4.1, TP10.1, U1.1, U2.8 (VIN+)
+BATT: +BATT.1, U1.2
/Monitoring/+3.3_IN: C1.1, C2.1, J6.1, R2.1, R3.1, U2.1 (A1), U2.5 (VS)
/TPS_Regulators/BOOT_3.3: C5.2, U3.1 (BOOT)
/TPS_Regulators/BOOT_5: C6.2, U4.1 (BOOT)
/TPS_Regulators/PH_3.3: C5.1, D2.1 (K), U3.8 (PH), U5.2
/TPS_Regulators/PH_5: C6.1, D3.1 (K), U4.8 (PH), U6.2
/TPS_Regulators/VIN_3.3: C3.1, JP2.2 (B), U3.7 (VIN)
/TPS_Regulators/VIN_5: C4.1, JP3.2 (B), U4.7 (VIN)
/TPS_Regulators/VS_3.3: R5.2, R6.1, U3.4 (VSENSE)
/TPS_Regulators/VS_5: R7.2, R8.1, U4.4 (VSENSE)
GND: +3.3V#2.2, +3.3V#3.2, +5V#2.2, +5V#3.2, C1.2, C2.2, C3.2, C4.2, D2.2 (A), D3.2 (A), GND.1, GND#2.1, GND#3.1, GND#4.1, J6.2, R1.2, R6.2, R8.2, U2.2 (A0), U2.6 (GND), U3.6 (GND), U3.9 (PowerPAD), U4.6 (GND), U4.9 (PowerPAD), U7.2, U8.2
LOAD: JP2.1 (A), JP3.1 (A), M_LOAD.1, M_LOAD#2.1, M_LOAD#3.1, R4.2, U2.7 (VIN-)
unnamed: D1.2 (A), JP1.2 (B)
unnamed: D1.1 (K), R1.1
SCL: J5.2, R3.2, U2.4 (SCL)
SDA: J5.1, R2.2, U2.3 (SDA)

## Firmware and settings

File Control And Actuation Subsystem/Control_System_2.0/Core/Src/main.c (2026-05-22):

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
/* Includes ------------------------------------------------------------------*/
#include "main.h"

/* USER CODE BEGIN Includes */
#include "battery.h"
#include "ToF.h"
#include "Sonar.h"
#include <stdio.h>
#include "telemetry.h"
#include "temp_sensor.h"
#include "mission_rx.h"
/* USER CODE END Includes */

/* USER CODE BEGIN PTD */
/* Telemetry pacing */
#define TELEM_PERIOD_MS  500u
uint32_t last_telem_ms = 0;
/* USER CODE END PTD */

/* USER CODE BEGIN PD */
#define MIN 65 //Minimum position of plunger of 4cm
#define MAX 100 //Maximum position of plunger of 12cm
/* USER CODE END PD */

ADC_HandleTypeDef hadc1;
DMA_HandleTypeDef hdma_adc1;

I2C_HandleTypeDef hi2c1;
I2C_HandleTypeDef hi2c2;

RTC_HandleTypeDef hrtc;

TIM_HandleTypeDef htim3;
TIM_HandleTypeDef htim4;

UART_HandleTypeDef huart1;
UART_HandleTypeDef huart2;
UART_HandleTypeDef huart3;

/* USER CODE BEGIN PV */
uint32_t current_time;
BatteryData_t bat;
uint32_t prev_time;
int mission_init = 0;
uint32_t t_begin = 0;
int time_saved = 0;
uint32_t time_elapsed = 0;
uint32_t current = 0;
int mission_complete = 0;

/* ---- Live sensor state: refreshed by UpdateSensors(), readable anywhere ---- */
float    soc          = 0.0f;     /* battery state of charge, % */
uint16_t mm           = 0;        /* ToF (plunger position), mm */
uint16_t sonar_dist   = 0;        /* sonar (obstacle distance), mm */
Sonar_Handle g_sonar;             /* global sonar handle */

RTC_TimeTypeDef sTime;
RTC_DateTypeDef sDate;

/* USER CODE END PV */

void SystemClock_Config(void);
static void MX_GPIO_Init(void);
static void MX_DMA_Init(void);
static void MX_ADC1_Init(void);
static void MX_RTC_Init(void);
static void MX_TIM3_Init(void);
static void MX_TIM4_Init(void);
static void MX_USART2_UART_Init(void);
static void MX_I2C1_Init(void);
static void MX_I2C2_Init(void);
static void MX_USART1_UART_Init(void);
static void MX_USART3_UART_Init(void);
/* USER CODE BEGIN 0 */

/* Send a telemetry packet at most once every TELEM_PERIOD_MS.
   Non-blocking: returns immediately if it's not yet time. */
static void Telemetry_Tick(void)
{
    uint32_t now = HAL_GetTick();
    if ((now - last_telem_ms) < TELEM_PERIOD_MS) {
        return;
    }
    last_telem_ms = now;

    /* MCU internal temp isn't wired up here — pass the sentinel.
       If you later sample ADC1 (TEMPSENSOR channel), replace this. */
    float mcu_temp = TempSensor_ReadC();
    Telemetry_Send(&bat, mm, sonar_dist, mcu_temp);
}

static void UpdateSensors(void)
{
    /* Battery — rate-limited internally, safe to call often */
    Battery_Update();
    Battery_GetData(&bat);
    soc = bat.soc_pct;

    /* ToF (plunger position) */
    uint16_t tof = ToF_ReadDistance(&hi2c2);
    if (tof > 0) {
        mm = tof;
    }

    /* Sonar (obstacle distance) — keep last good reading on error */
    uint16_t sd = 0;
    Sonar_GetDistance(&g_sonar, &sd);
        sonar_dist = sd;

}
/*A function that stops motor from over exceeding limits*/
void stop_motor(void)
{
    TIM3->CCR1 = 0;
    TIM4->CCR1 = 0;
    UpdateSensors();   /* keep state fresh even at stop */
    Telemetry_Tick();
}

/*Function to check initial plunger position and force it to minimum so that upon mission start we can pull in water and descend*/
void Force_plunger_min(void)
{
    UpdateSensors();
    while (mm > MIN) {
        TIM4->CCR1 = 1599;
        UpdateSensors();
        Telemetry_Tick();
        /* Safety: bail out if battery dies mid-move */
        if (soc < 20) break;

        HAL_Delay(2);
    }
    stop_motor();
}

/* Push plunger to MAX (pulls water in) → platform sinks. */
void descend(void)
{
    UpdateSensors();
    while (mm < MAX) {
        TIM3->CCR1 = 1599;
        UpdateSensors();
        Telemetry_Tick();
        /* Safety: stop if battery dies */
        if (soc < 20) break;

        HAL_Delay(2);
    }
    stop_motor();
}

/* Pull plunger back toward MIN → platform rises.
   Exits early if an obstacle is detected by the sonar. */
void ascend(void)
{
    UpdateSensors();
    while (mm > MIN && sonar_dist > 1000) {
        TIM4->CCR1 = 1599;
        UpdateSensors();
        Telemetry_Tick();
        HAL_Delay(2);
    }
    stop_motor();
}



void HAL_GPIO_EXTI_Callback(uint16_t GPIO_Pin)
 {

	current_time = HAL_GetTick();
 	if ((GPIO_Pin == Pushbutton_Pin) && (current_time - prev_time > 10))
 	{


 		//TODO: Update mission initiation status
 		mission_init = 1;


 		prev_time = current_time;

 	}
 }

uint32_t to_seconds(uint8_t hours, uint8_t minutes, uint8_t seconds) {
    return (hours * 3600) + (minutes * 60) + seconds;
}

/* ============================================================
 *  ONE-SHOT CALIBRATION
 *  Comment out this whole block after running it once.
 *  ============================================================
 *  Procedure:
 *    1. Place sensor exactly TOF_CAL_NEAR_REF_MM from a flat target.
 *    2. Power on / reset — onboard LED stays ON for 5 s (get ready).
 *    3. LED blinks fast while it captures 50 samples (~3 s).
 *    4. LED stays ON for 5 s — move target to TOF_CAL_FAR_REF_MM.
 *    5. LED blinks fast again — captures 50 more samples.
 *    6. LED gives 3 quick flashes = saved, or stays on solid = failed.
 *    7. Comment out the call and reflash.
 * ============================================================ */
static void RunOneShotCalibration(I2C_HandleTypeDef *hi2c)
{
    /* Stage 1: prompt for NEAR target */
    HAL_GPIO_WritePin(GPIOA, LD2_Pin, GPIO_PIN_SET);  /* LED ON (active high on Nucleo) */
    HAL_Delay(5000);

    /* Capture NEAR */
    HAL_GPIO_WritePin(GPIOA, LD2_Pin, GPIO_PIN_RESET);  /* LED OFF */
    uint16_t measured_near = ToF_AverageRaw(hi2c, TOF_CAL_SAMPLES);

    /* Stage 2: prompt for FAR target */
    HAL_GPIO_WritePin(GPIOA, LD2_Pin, GPIO_PIN_SET);  /* LED ON */
    HAL_Delay(5000);

    /* Capture FAR */
    HAL_GPIO_WritePin(GPIOA, LD2_Pin, GPIO_PIN_RESET);  /* LED OFF */
    uint16_t measured_far = ToF_AverageRaw(hi2c, TOF_CAL_SAMPLES);

    /* Compute + persist */
    uint8_t ok = ToF_Calibrate(measured_near, measured_far,
                               TOF_CAL_NEAR_REF_MM, TOF_CAL_FAR_REF_MM);

    if (ok)
    {
        /* 3 quick flashes = success */
        for (int i = 0; i < 6; i++)
        {
            HAL_GPIO_TogglePin(GPIOA, LD2_Pin);
            HAL_Delay(100);
        }
        HAL_GPIO_WritePin(GPIOA, LD2_Pin, GPIO_PIN_SET);  /* LED OFF */
    }
    else
    {
        /* Solid ON = failure indication */
        HAL_GPIO_WritePin(GPIOA, LD2_Pin, GPIO_PIN_RESET);
        while (1) {}  /* halt so you notice */
    }
}

static void ErrorBlink(void)
{
    while (1)
    {
    	HAL_GPIO_TogglePin(GPIOA, LD2_Pin);
        HAL_Delay(200);
    }
}
/* USER CODE END 0 */

/**
  * @brief  The application entry point.
  * @retval int
  */
int main(void)
{

  /* MCU Configuration--------------------------------------------------------*/

  /* Reset of all peripherals, Initializes the Flash interface and the Systick. */
  HAL_Init();

  /* Configure the system clock */
  SystemClock_Config();

  /* Initialize all configured peripherals */
  MX_GPIO_Init();
  MX_DMA_Init();
  MX_ADC1_Init();
  MX_RTC_Init();
  MX_TIM3_Init();
  MX_TIM4_Init();
  MX_USART2_UART_Init();
  MX_I2C1_Init();
  MX_I2C2_Init();
  MX_USART1_UART_Init();
  MX_USART3_UART_Init();
  /* USER CODE BEGIN 2 */
  HAL_TIM_PWM_Start(&htim3, TIM_CHANNEL_1);
    HAL_TIM_PWM_Start(&htim4, TIM_CHANNEL_1);




    HAL_GPIO_WritePin(XShunt_GPIO_Port, XShunt_Pin, GPIO_PIN_RESET);
    HAL_Delay(10);
    HAL_GPIO_WritePin(XShunt_GPIO_Port, XShunt_Pin, GPIO_PIN_SET);
    HAL_Delay(10);


    if (ToF_Init(&hi2c2) != HAL_OK)
        {
            ErrorBlink();
        }

  	if(Battery_Init(&hi2c1) != HAL_OK){
  		Error_Handler();
  	}

  	if (Sonar_Init(&g_sonar, &huart1) != SONAR_OK) {
  	      /* Sonar init failed — hang. Swap for ErrorBlink() if you'd rather see it. */
  	      while (1) { }
  	  }

  	Telemetry_Init(&huart3);

  	TempSensor_Init(&hadc1);

  	MissionRx_Init(&huart3);

  	HAL_Delay(1000);

  	HAL_GPIO_WritePin(GPIOA, LD2_Pin, 0);

    	    	/* Infinite loop */
  	  /* USER CODE BEGIN WHILE */
  	  while (1)
  	  {
  	      /* RTC snapshot — GetDate must follow GetTime on F4 */
  	      HAL_RTC_GetTime(&hrtc, &sTime, RTC_FORMAT_BIN);
  	      HAL_RTC_GetDate(&hrtc, &sDate, RTC_FORMAT_BIN);

  	      /* Refresh all sensors */
  	      UpdateSensors();

  	      Telemetry_Tick();

  	      /* ---- Flow diagram begins here ---- */

  	      /* Gate: Mission Initialized? */
  	      if (!missionInit) {
  	          HAL_Delay(50);
  	          continue;
  	      }

  	    HAL_GPIO_WritePin(GPIOA, LD2_Pin, 1);

  	  /* Gate: Battery Enough? */
  	    	      if (soc <= 30 || mission_complete) {
  	    	          stop_motor();
  	    	          /* If mission is done AND no obstacles, ascend home.
  	    	             Also ascend if battery got low. */
  	    	          if ((mission_complete && sonar_dist > 1000) || soc < 20) {
  	    	              ascend();
  	    	          }
  	    	          HAL_Delay(100);
  	    	          continue;
  	    	      }

  	    	      /* Gate: Plunger at MIN? */
  	    	      if (mm >= MIN) {
  	    	          Force_plunger_min();   /* falls through to DESCEND on next iter */
  	    	          continue;
  	    	      }

  	    	      /* DESCEND */
  	    	      descend();

  	    	      /* Mission timer starts the first time we successfully descended */
  	    	      if (time_saved == 0) {
  	    	          t_begin = to_seconds(sTime.Hours, sTime.Minutes, sTime.Seconds);
  	    	          time_saved = 1;
  	    	      }

  	    	      /* While submerged, keep refreshing time + sensors until mission timeout */
  	    	      while (!mission_complete && soc >= 20) {
  	    	          HAL_RTC_GetTime(&hrtc, &sTime, RTC_FORMAT_BIN);
  	    	          HAL_RTC_GetDate(&hrtc, &sDate, RTC_FORMAT_BIN);
  	    	          UpdateSensors();
  	    	          Telemetry_Tick();

  	    	          current = to_seconds(sTime.Hours, sTime.Minutes, sTime.Seconds);
  	    	          time_elapsed = (current < t_begin)
  	    	                       ? (86400 - t_begin) + current
  	    	                       : (current - t_begin);

  	    	          if (time_elapsed >= 30) {
  	    	              mission_complete = 1;
  	    	          }

  	    	          HAL_Delay(100);
  	    	      }

  	    	      /* Mission done (or battery low) → ASCEND if path is clear */
  	    	      stop_motor();
  	    	      if ((mission_complete && sonar_dist > 1000) || soc < 20) {
  	    	          ascend();
  	    	      }

  	         /* USER CODE BEGIN 3 */
  }
  /* USER CODE END 3 */
}

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


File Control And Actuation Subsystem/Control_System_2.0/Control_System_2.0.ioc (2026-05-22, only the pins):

Mcu.UserName=STM32F446RETx
PA10.Signal=USART1_RX
PA13.GPIO_Label=TMS
PA13.Signal=SYS_JTMS-SWDIO
PA14.GPIO_Label=TCK
PA14.Signal=SYS_JTCK-SWCLK
PA2.GPIO_Label=USART_TX
PA2.Signal=USART2_TX
PA3.GPIO_Label=USART_RX
PA3.Signal=USART2_RX
PA5.GPIO_Label=LD2 [Green Led]
PA5.Signal=GPIO_Output
PA6.Signal=S_TIM3_CH1
PA8.GPIO_Label=XShunt
PA8.Signal=GPIO_Output
PA9.Signal=USART1_TX
PB10.Signal=I2C2_SCL
PB3.GPIO_Label=SWO
PB3.Signal=SYS_JTDO-SWO
PB6.Signal=S_TIM4_CH1
PB7.Signal=I2C1_SDA
PB8.Signal=I2C1_SCL
PC10.Signal=USART3_TX
PC12.Signal=I2C2_SDA
PC13.GPIO_Label=Pushbutton
PC13.Signal=GPXTI13
PC14-OSC32_IN.Signal=RCC_OSC32_IN
PC15-OSC32_OUT.Signal=RCC_OSC32_OUT
PC5.Signal=USART3_RX
PH0-OSC_IN.Signal=RCC_OSC_IN
PH1-OSC_OUT.Signal=RCC_OSC_OUT

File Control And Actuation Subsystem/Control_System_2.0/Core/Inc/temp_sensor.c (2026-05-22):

#include "temp_sensor.h"

/* Factory calibration values for STM32F446 (RM0390) */
#define TS_CAL1     (*(uint16_t *)0x1FFF7A2C)   /* raw ADC at 30°C  */
#define TS_CAL2     (*(uint16_t *)0x1FFF7A2E)   /* raw ADC at 110°C */

static uint16_t adc_buf[1];   /* DMA target — one sample */

void TempSensor_Init(ADC_HandleTypeDef *hadc)
{
    HAL_ADC_Start_DMA(hadc, (uint32_t *)adc_buf, 1);
}

float TempSensor_ReadC(void)
{
    uint16_t raw = adc_buf[0];

    /* Linear interpolation between factory cal points */
    return ((110.0f - 30.0f) / (float)(TS_CAL2 - TS_CAL1))
           * ((float)raw - (float)TS_CAL1)
           + 30.0f;
}

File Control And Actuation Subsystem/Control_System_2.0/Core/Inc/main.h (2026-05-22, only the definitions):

#define Pushbutton_Pin GPIO_PIN_13
#define Pushbutton_GPIO_Port GPIOC
#define Pushbutton_EXTI_IRQn EXTI15_10_IRQn
#define USART_TX_Pin GPIO_PIN_2
#define USART_TX_GPIO_Port GPIOA
#define USART_RX_Pin GPIO_PIN_3
#define USART_RX_GPIO_Port GPIOA
#define LD2_Pin GPIO_PIN_5
#define LD2_GPIO_Port GPIOA
#define XShunt_Pin GPIO_PIN_8
#define XShunt_GPIO_Port GPIOA
#define TMS_Pin GPIO_PIN_13
#define TMS_GPIO_Port GPIOA
#define TCK_Pin GPIO_PIN_14
#define TCK_GPIO_Port GPIOA
#define SWO_Pin GPIO_PIN_3
#define SWO_GPIO_Port GPIOB

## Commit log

2026-05-18 Ground works
2026-05-18 Add README for Sensory Subsystem firmware
    This README provides an overview of the Sensory Subsystem firmware for the MEERKAT AUV, detailing sensor integration, hardware configuration, and core file structure.
2026-05-18 Revise README with updated sensor information
    Updated sensor specifications and calibration details in the README.
2026-05-22 Sensor files extracted
2026-05-22 Created README for Power Subsystem
    Add detailed documentation for the Power Subsystem, including hardware specifications, PCB layout, and firmware module information.
2026-05-22 Added README for Control & Actuation Subsystem firmware
    Added detailed README for Control & Actuation Subsystem firmware, including overview, hardware configuration, mission state machine, core file structure, calibration instructions, and troubleshooting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
2026-05-22 Added README for Housing Subsystem
    Added detailed README for Housing Subsystem including overview, parts, internal layout, sealing strategy, manufacturing notes, file opening instructions, and status.

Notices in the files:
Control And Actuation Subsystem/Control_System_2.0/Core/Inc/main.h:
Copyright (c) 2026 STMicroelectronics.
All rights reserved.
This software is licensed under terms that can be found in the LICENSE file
